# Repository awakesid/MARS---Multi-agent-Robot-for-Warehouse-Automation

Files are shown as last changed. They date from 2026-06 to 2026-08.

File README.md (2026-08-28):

# M.A.R.S — Multi Agent Robot System for Warehouse Automation

Modular multi-robot warehouse automation system using sensor fusion (encoders + overhead camera/ArUco) for localization, with ROS 2 based central coordination and ESP32-based robot firmware.

## Overview

- Differential-drive robots with ESP32 microcontrollers, encoder-based odometry, and servo grippers
- Overhead camera + ArUco markers for global pose estimation of robots, loads, and dropzones
- ROS 2 central controller handles task allocation, path planning, collision avoidance
- Robot ↔ central controller communication over UDP (JSON commands)
- Supports single/multi-robot operation, priority-based and thread-based task execution, single/double dropzone configurations

## System Architecture

```
Overhead Camera → aruco_detector (OpenCV) → /bot_poses, /loads, /dropzone
                                                      ↓
                                              task_manager (ROS 2)
                                        (task allocation, collision avoidance, navigation)
                                                      ↓
                                          UDP (JSON) ↔ ESP32 robots
```

## Hardware

- ESP32-WROOM / ESP32-S3
- N20 DC motors with encoders
- L293D dual H-bridge motor driver
- Servo gripper
- Li-Po battery
- Custom double-sided PCB (KiCad design, in-house etched)
- 3D printed chassis (Fusion 360 + Bambu Lab printer)

## Software Stack

- **Firmware**: C++ (Arduino/ESP32), non-blocking UDP + Telnet handlers, PID for straight-line motion
- **Central Controller**: ROS 2 (Python/C++), OpenCV for ArUco detection
- **Communication**: ROS 2 topics (internal), UDP/WiFi (robot control)

## Repository Structure

```
/firmware        # ESP32 robot firmware (motor control, encoder PID, UDP command handling)
/ros2_ws          # ROS 2 packages: camera_node, aruco_detector, task_manager
/pcb              # KiCad PCB design files
/cad              # Fusion 360 chassis design files
/docs             # Report, diagrams, results
```

## Firmware Command Protocol

Robots listen on a dedicated UDP port for JSON commands:

```json
{"id": 1, "cmd": "FORWARD", "dist": 200}
{"id": 1, "cmd": "TURN_L", "angle": 90}
{"id": 1, "cmd": "GRAB"}
```

Supported commands: `FORWARD`, `BACKWARD`, `TURN_L`, `TURN_R`, `GRAB`, `RELEASE`, `STOP`
Each command receives an `ack` on receipt and a `done` reply on completion. Odometry is broadcast at 10 Hz.

## Setup

### Firmware
1. Open `/firmware` in Arduino IDE / PlatformIO
2. Set `BOT_ID`, WiFi credentials, and target UDP port per robot
3. Flash to ESP32

### Central Controller
1. Requires ROS 2 (tested on Humble/Iron), OpenCV, `opencv-contrib` (ArUco module)
2. Build workspace:
   ```
   cd ros2_ws
   colcon build
   source install/setup.bash
   ```
3. Launch nodes:
   ```
   ros2 launch mars_bringup mars.launch.py
   ```

Thread-based multi-robot execution with double dropzone gave the best throughput; single dropzone increases collision risk and coordination overhead.

## Team
- Amrit Kumar Banjade
- Laxmi Prasad Upadhyaya
- Siddartha Gupta
- Sumit Sigdel

Department of Electronics and Computer Engineering, Pashchimanchal Campus, IOE, Tribhuvan University
Supervisor: Asst. Prof. Er. Hom Nath Tiwari

For a more detailed description, you can refer `MARS_report.pdf`

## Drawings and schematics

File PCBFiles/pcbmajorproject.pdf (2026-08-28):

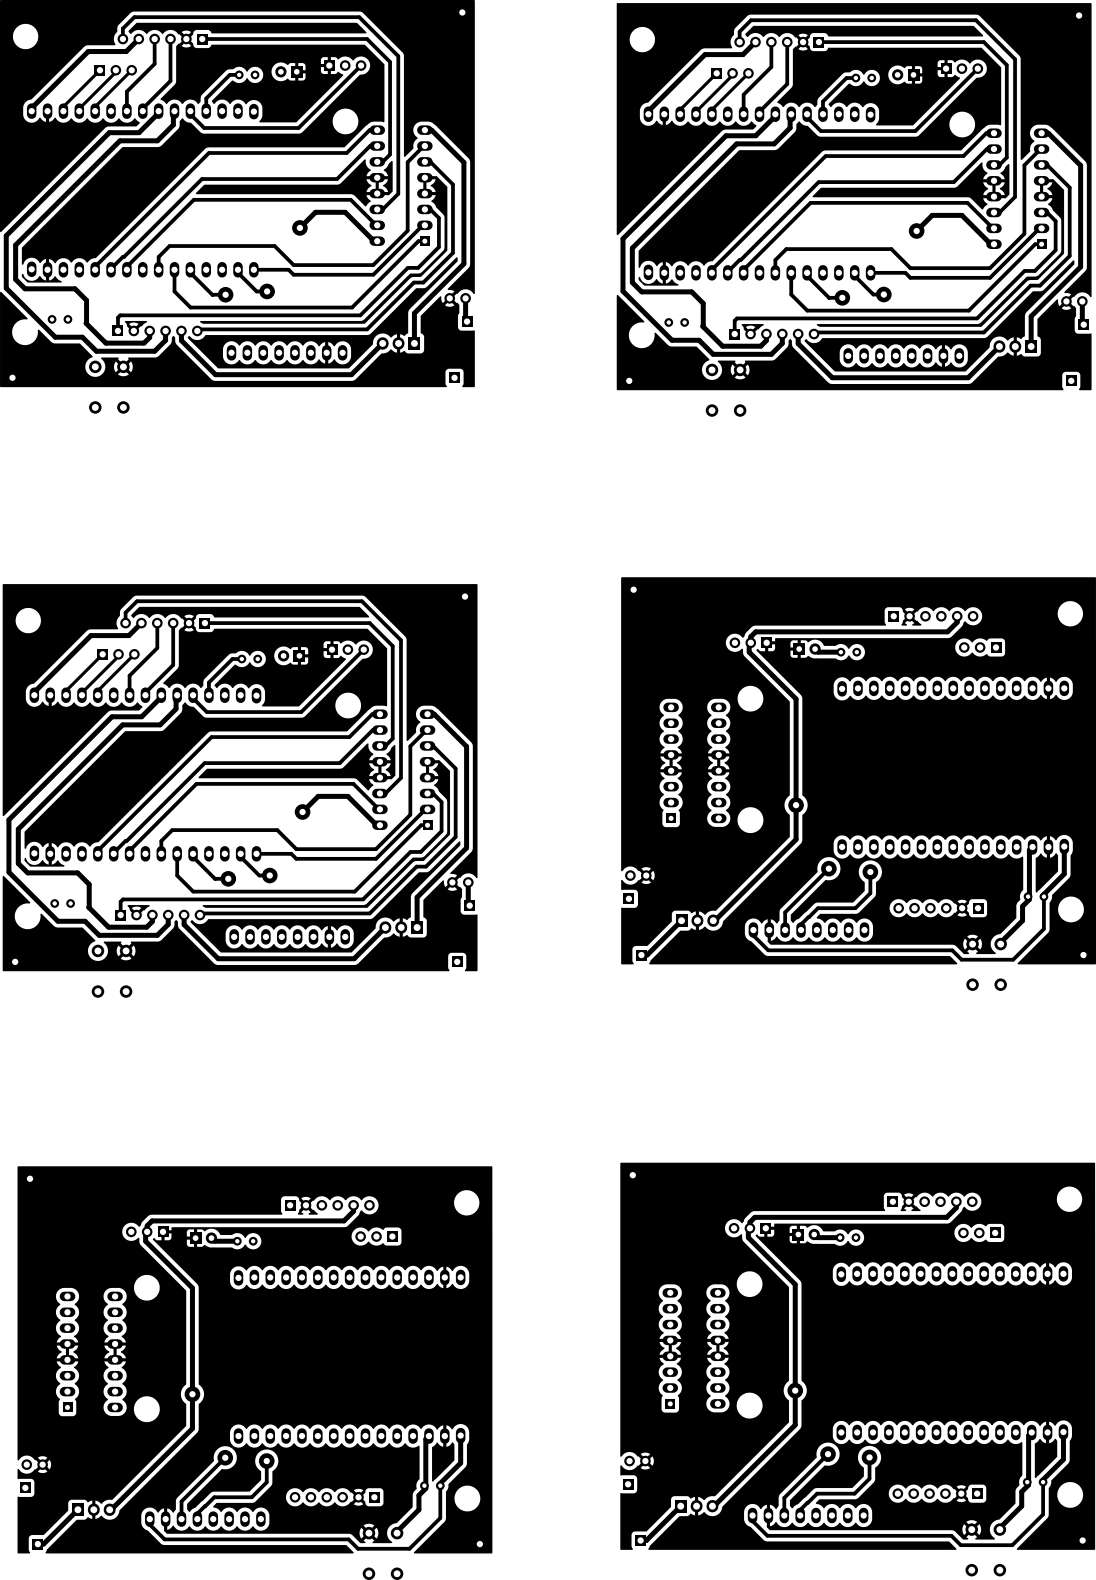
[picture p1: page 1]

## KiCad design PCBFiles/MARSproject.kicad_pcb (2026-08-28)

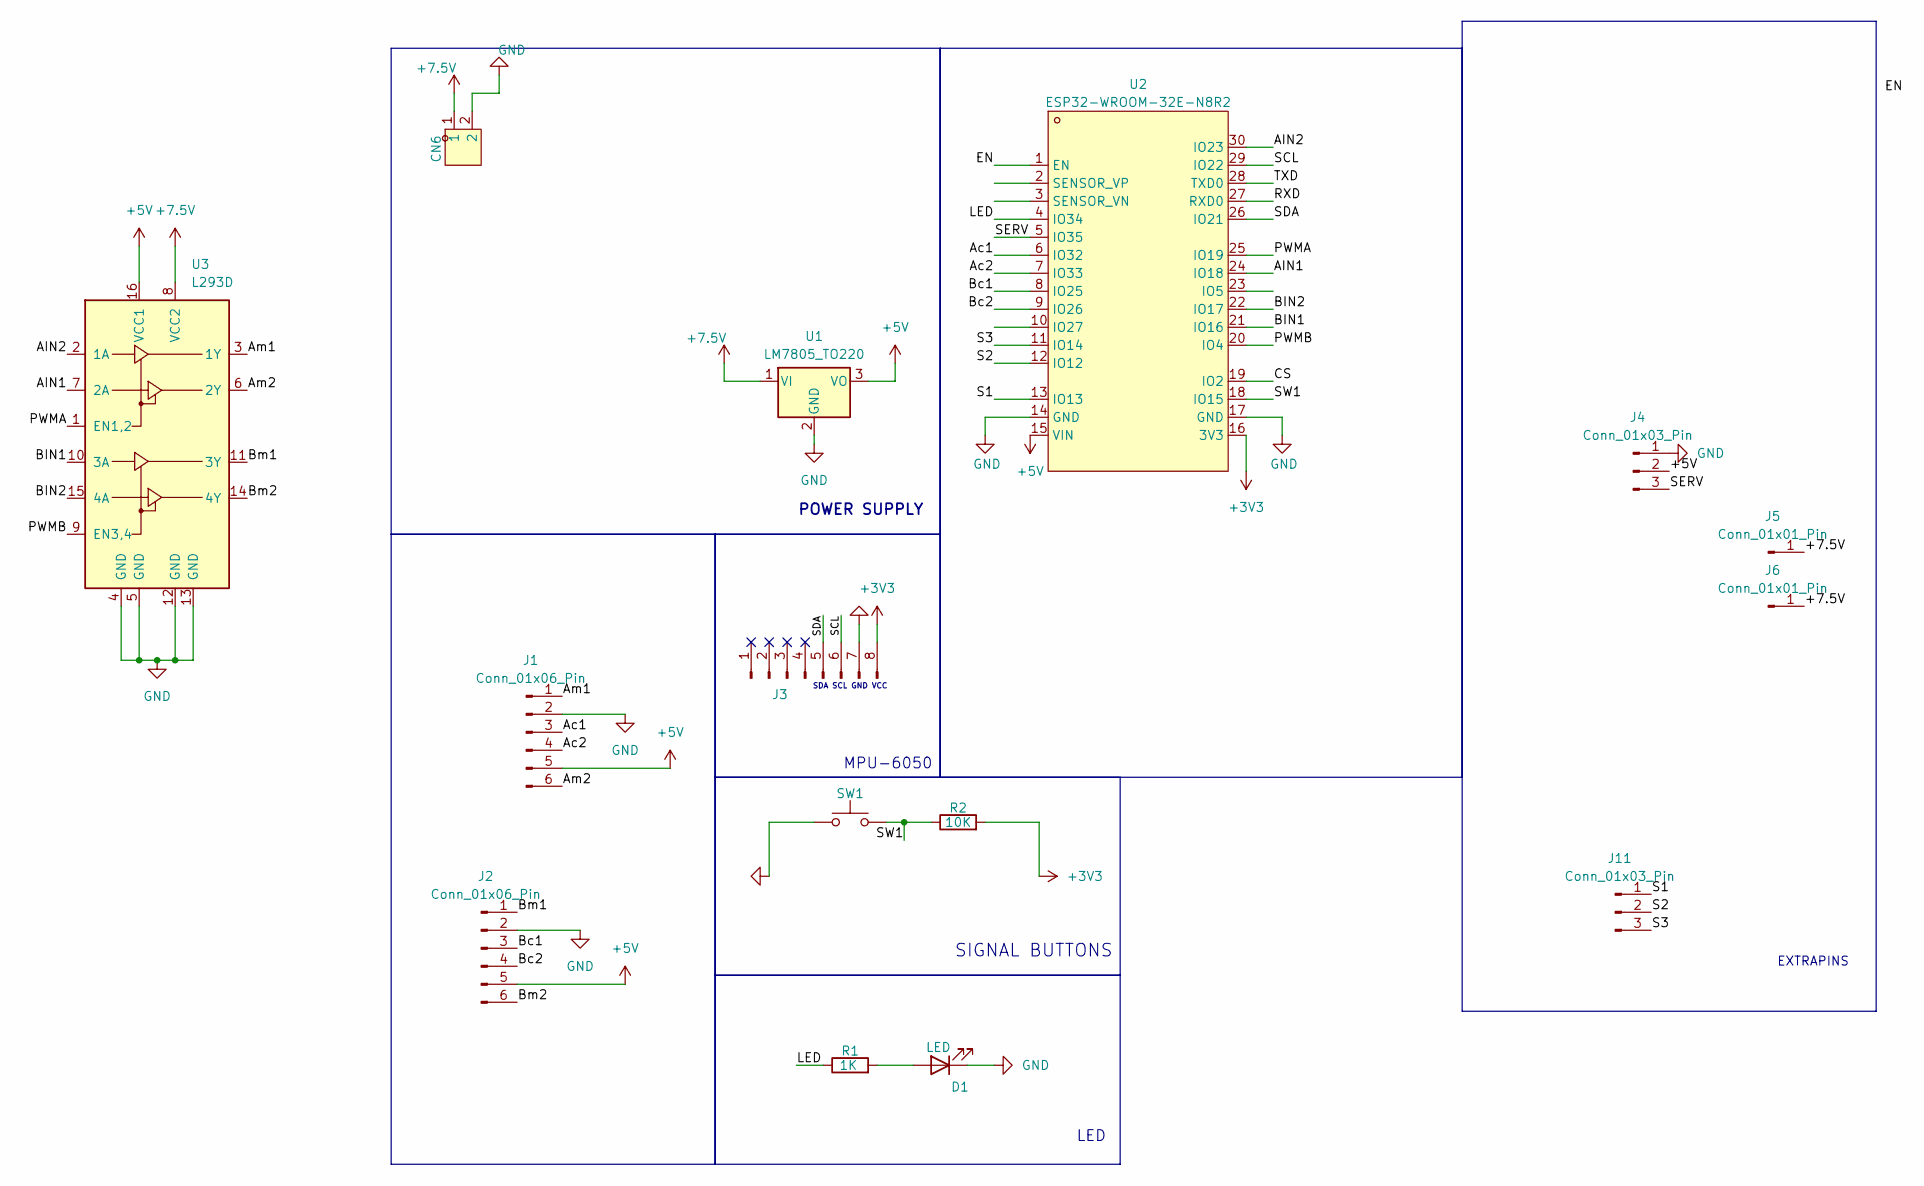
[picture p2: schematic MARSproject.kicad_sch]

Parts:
CN6: B2B-XH-A (LF)(SN); CONN-TH_B2B-XH-A-LF-SN; LCSC Part C158012
D1: LED; LED_D1.8mm_W3.3mm_H2.4mm
J1, J2: Conn_01x06_Pin; PinHeader_1x06_P2.54mm_Vertical
J3: Conn_01x08_Pin; PinHeader_1x08_P2.54mm_Vertical
J4, J11: Conn_01x03_Pin; PinHeader_1x03_P2.54mm_Vertical
J5, J6: Conn_01x01_Pin; PinHeader_1x01_P2.54mm_Vertical
R1: 1K; R_Axial_DIN0204_L3.6mm_D1.6mm_P2.54mm_Vertical
R2: 10K; R_Axial_DIN0204_L3.6mm_D1.6mm_P2.54mm_Vertical
SW1: SW_Push; SW_PUSH_6mm_H4.3mm
U1: LM7805_TO220; TO-220-3_Vertical
U2: ESP32-WROOM-32E-N8R2; esp32 dev board; LCSC Part C5361945
U3: L293D; DIP-16_W7.62mm

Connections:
+3V3: J3.8, R2.2, U2.16 (3V3)
+5V: J1.5, J2.5, J4.2, U1.3 (VO), U2.15 (VIN), U3.16 (VCC1)
+7.5V: CN6.1, J5.1, J6.1, U1.1 (VI), U3.8 (VCC2)
/AIN1: U2.24 (IO18), U3.7 (2A)
/AIN2: U2.30 (IO23), U3.2 (1A)
/Ac1: J1.3, U2.6 (IO32)
/Ac2: J1.4, U2.7 (IO33)
/Am1: J1.1, U3.3 (1Y)
/Am2: J1.6, U3.6 (2Y)
/BIN1: U2.21 (IO16), U3.10 (3A)
/BIN2: U2.22 (IO17), U3.15 (4A)
/Bc1: J2.3, U2.8 (IO25)
/Bc2: J2.4, U2.9 (IO26)
/Bm1: J2.1, U3.11 (3Y)
/Bm2: J2.6, U3.14 (4Y)
/CS: U2.19 (IO2)
/EN: U2.1 (EN)
/LED: R1.1, U2.4 (IO34)
/PWMA: U2.25 (IO19), U3.1 (EN1,2)
/PWMB: U2.20 (IO4), U3.9 (EN3,4)
/RXD: U2.27 (RXD0)
/S1: J11.1, U2.13 (IO13)
/S2: J11.2, U2.12 (IO12)
/S3: J11.3, U2.11 (IO14)
/SCL: J3.6, U2.29 (IO22)
/SDA: J3.5, U2.26 (IO21)
/SERV: J4.3, U2.5 (IO35)
/SW1: R2.1, SW1.2, U2.18 (IO15)
/TXD: U2.28 (TXD0)
GND: CN6.2, D1.1 (K), J1.2, J2.2, J3.7, J4.1, SW1.1, U1.2 (GND), U2.14 (GND), U2.17 (GND), U3.4 (GND), U3.5 (GND), U3.12 (GND), U3.13 (GND)
unnamed: D1.2 (A), R1.2

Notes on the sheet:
SDA SCL GND VCC
SIGNAL BUTTONS
MPU-6050
POWER SUPPLY
EXTRAPINS
LED

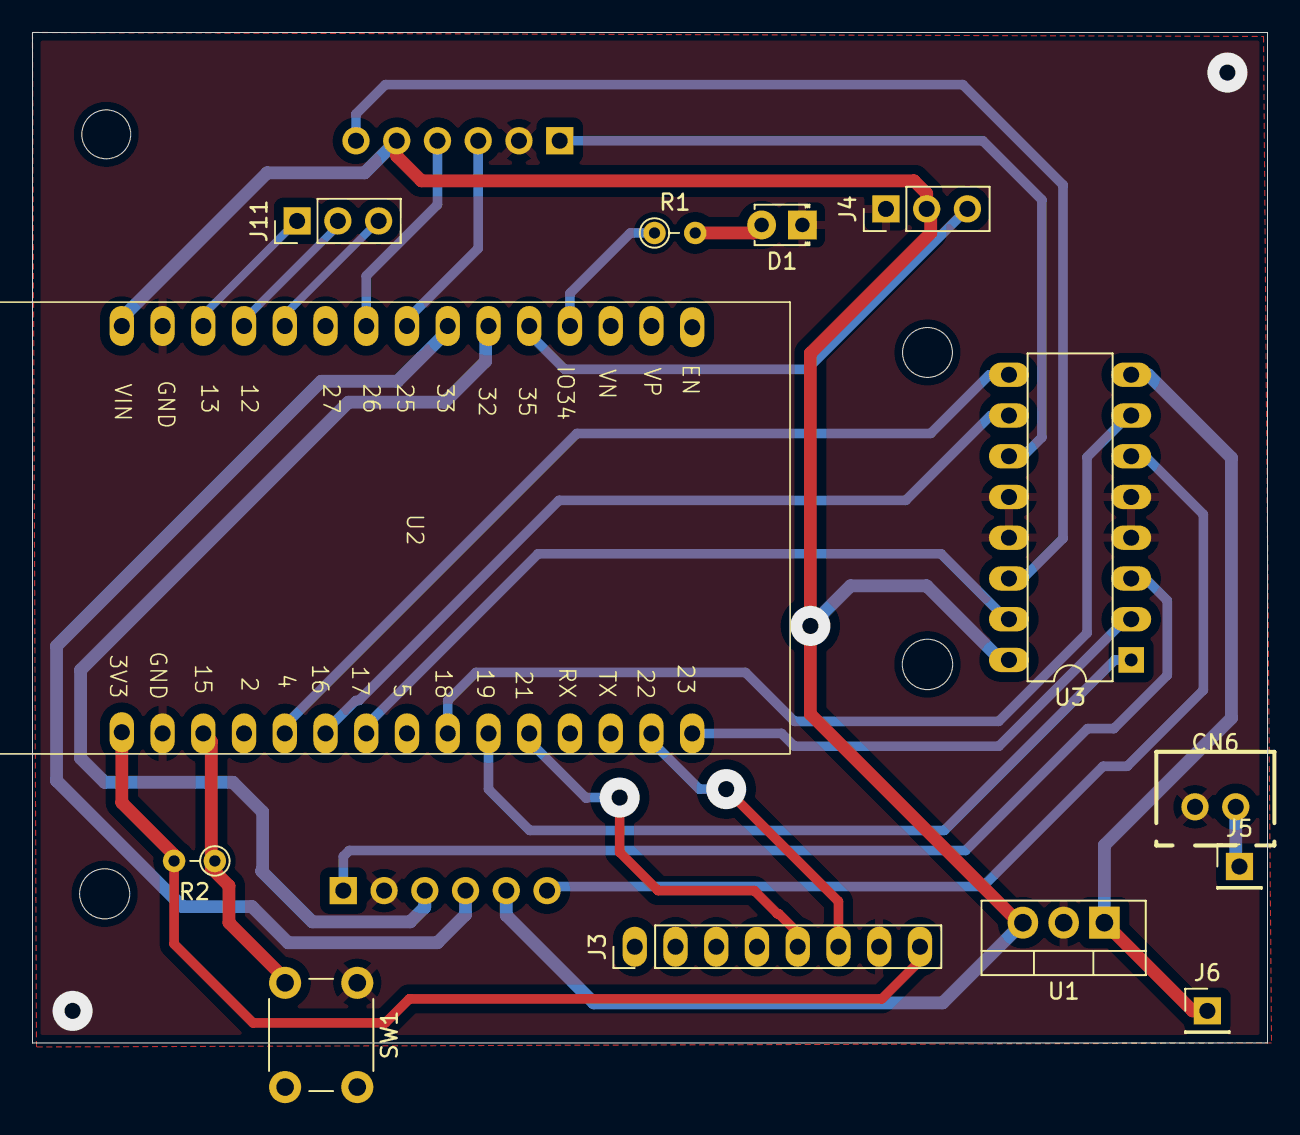
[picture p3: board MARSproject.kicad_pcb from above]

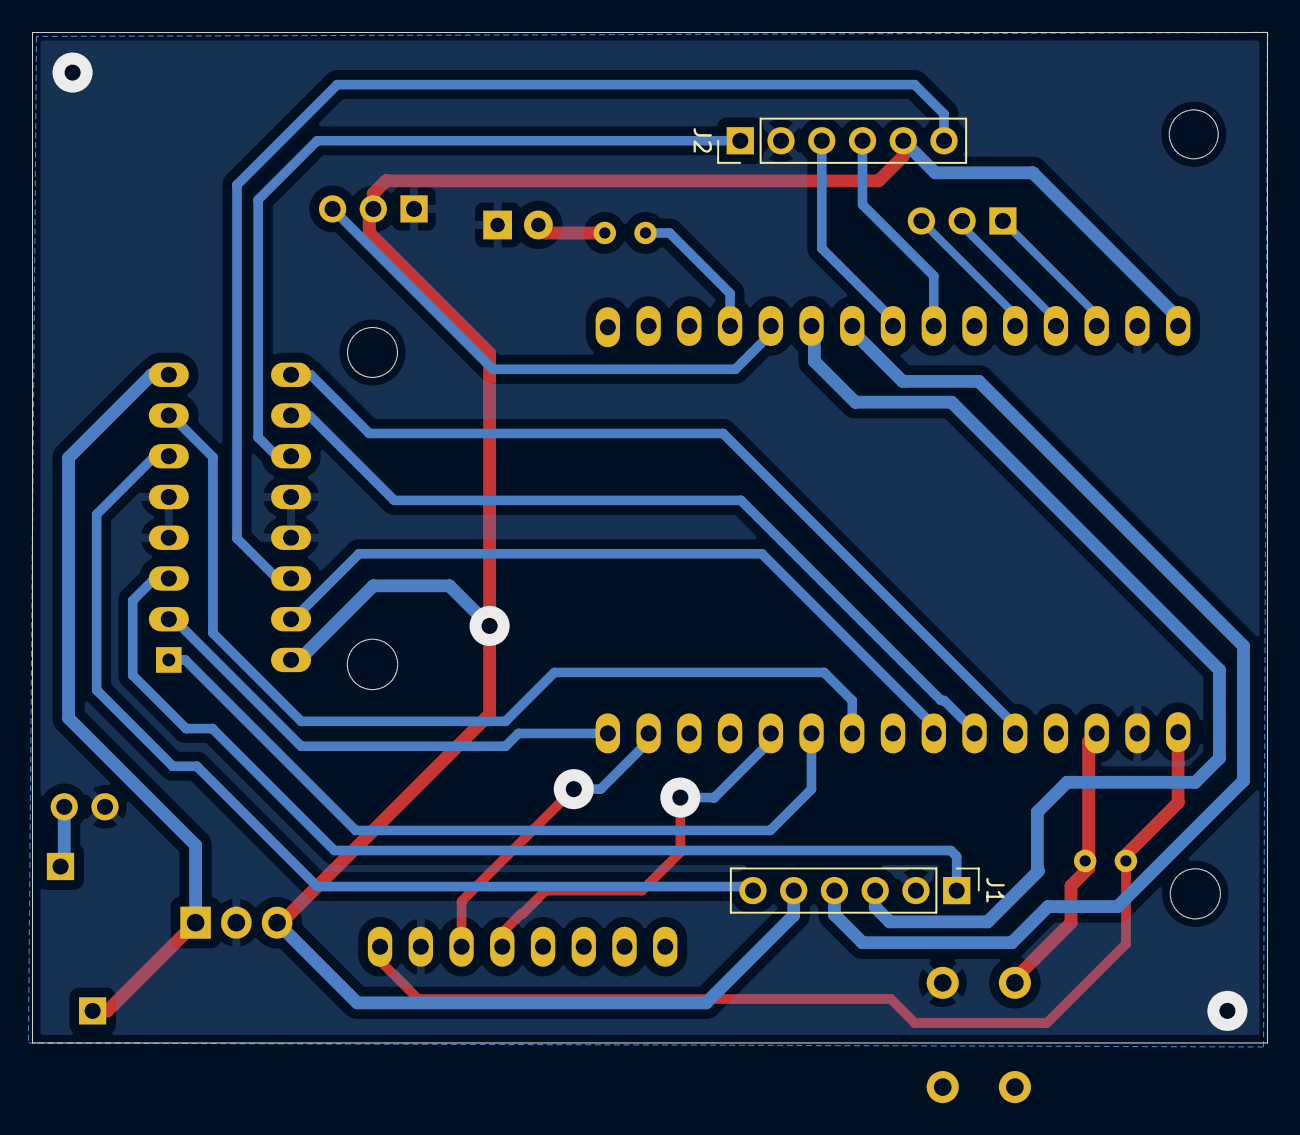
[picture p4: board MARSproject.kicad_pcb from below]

Board: 2 copper layers, 77.0 x 63.0 mm, 15 parts (2 on the bottom side), 27 nets.

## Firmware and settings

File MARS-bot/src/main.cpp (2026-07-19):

#include <Arduino.h>
#include <WiFi.h>
#include <ArduinoJson.h>


// ─── WiFi Config ─────────────────────────────────────────────────
const char* SSID     = "your ssid";
const char* PASSWORD = "your password";
const int   UDP_PORT = 4210;

// ─── Bot Identity ────────────────────────────────────────────────
const int BOT_ID = 1;  // change per bot: 1, 2, 3

// ─── Motor Pins ───────────────────────────────────────────────────
#define R_IN1   18
#define R_IN2   23
#define R_EN    19
#define L_IN1   16
#define L_IN2   17
#define L_EN    4

#define SERVO_PIN 14

// ─── Encoder Pins ────────────────────────────────────────────────
#define ENC_L_A  26
#define ENC_L_B  25
#define ENC_R_A  32
#define ENC_R_B  33

// ─── PWM ─────────────────────────────────────────────────────────
#define L_PWM_CH  0
#define R_PWM_CH  1
#define PWM_FREQ  5000
#define PWM_RES   8

#define SERVO_CH   2
#define SERVO_FREQ 50    // 50Hz standard servo

// ─── Robot Constants ─────────────────────────────────────────────
const float TICKS_PER_MM  = 6.48f;
const float TICKS_PER_DEG = 7.067f;
const int   BASE_SPEED    = 150;
const int   TURN_SPEED    = 120;
const int   MIN_SPEED     = 85;   // min PWM before motor stalls (L293D)

// ─── PID Gains (tunable via telnet) ──────────────────────────────
float Kp = 1.2f;
float Ki = 0.8f;
float Kd = 0.8f;

// ─── Encoder ─────────────────────────────────────────────────────
volatile long encL = 0;
volatile long encR = 0;

void IRAM_ATTR encL_ISR() {
  if (digitalRead(ENC_L_B)) encL++; else encL--;
}
void IRAM_ATTR encR_ISR() {
  if (digitalRead(ENC_R_B)) encR++; else encR--;
}

// ─── PID State ───────────────────────────────────────────────────
float pid_integral = 0;
float pid_last_err = 0;
unsigned long pid_last_time = 0;

// ─── Network ─────────────────────────────────────────────────────
WiFiUDP     udp;
WiFiServer  telnetServer(23);
WiFiClient  telnetClient;

IPAddress   remoteIP;
uint16_t    remotePort = 0;

// ─── Log (telnet + serial) ────────────────────────────────────────
void rlog(const char* format, ...) {
  char buf[256];
  va_list args;
  va_start(args, format);
  vsnprintf(buf, sizeof(buf), format, args);
  va_end(args);
  Serial.println(buf);
  if (telnetClient && telnetClient.connected())
    telnetClient.println(buf);
}

// ─── UDP Reply ────────────────────────────────────────────────────
void udpReply(const char* type, const char* extra = "") {
  if (remotePort == 0) return;
  char buf[128];
  snprintf(buf, sizeof(buf),
    "{\"id\":%d,\"type\":\"%s\",\"encL\":%ld,\"encR\":%ld%s}",
    BOT_ID, type, encL, encR, extra);
  udp.beginPacket(remoteIP, remotePort);
  udp.print(buf);
  udp.endPacket();
}


//---------------------------------------------
void servoSetup() {
  ledcSetup(SERVO_CH, SERVO_FREQ, 16);  // 16-bit for servo precision
  ledcAttachPin(SERVO_PIN, SERVO_CH);
}

void servoOpen() {   // 90 degrees
  ledcWrite(SERVO_CH, 7864);  // ~1.5ms pulse / 20ms * 65535
}

void servoClose() {  // 0 degrees  
  ledcWrite(SERVO_CH, 1738);  // ~0.5ms pulse / 20ms * 65535
}

// ─── Motor Control ───────────────────────────────────────────────
void stopMotors() {
  digitalWrite(L_IN1, LOW); digitalWrite(L_IN2, LOW);
  digitalWrite(R_IN1, LOW); digitalWrite(R_IN2, LOW);
  ledcWrite(L_PWM_CH, 0);
  ledcWrite(R_PWM_CH, 0);
}

void motorLeft(int spd) {
  if (spd >= 0) { digitalWrite(L_IN1, HIGH); digitalWrite(L_IN2, LOW); }
  else          { digitalWrite(L_IN1, LOW);  digitalWrite(L_IN2, HIGH); spd = -spd; }
  ledcWrite(L_PWM_CH, constrain(spd, 0, 255));
}

void motorRight(int spd) {
  if (spd >= 0) { digitalWrite(R_IN1, HIGH); digitalWrite(R_IN2, LOW); }
  else          { digitalWrite(R_IN1, LOW);  digitalWrite(R_IN2, HIGH); spd = -spd; }
  ledcWrite(R_PWM_CH, constrain(spd, 0, 255));
}

// ─── PID ─────────────────────────────────────────────────────────
void resetPID() {
  pid_integral = 0; pid_last_err = 0; pid_last_time = millis();
}

int pidCalc(float err) {
  unsigned long now = millis();
  float dt = (now - pid_last_time) / 1000.0f;
  if (dt < 0.001f) dt = 0.02f;
  pid_last_time = now;
  pid_integral += err * dt;
  float deriv = (err - pid_last_err) / dt;
  pid_last_err = err;
  return (int)constrain(Kp*err + Ki*pid_integral + Kd*deriv, -80, 80);
}

// ─── Odometry Send (10Hz) ─────────────────────────────────────────
unsigned long lastOdomMs = 0;
void sendOdom() {
  if (millis() - lastOdomMs < 100) return;
  lastOdomMs = millis();
  udpReply("odom");
}

// ════════════════════════════════════════════════════════════════
//  MOVE FORWARD
// ════════════════════════════════════════════════════════════════
void moveForward(float dist_mm, int speed) {
  long target = (long)(dist_mm * TICKS_PER_MM);
  encL = encR = 0;
  resetPID();
  rlog("[FWD] %.0fmm → %ld ticks", dist_mm, target);
  udpReply("ack");

  while (true) {
    long avg = (abs(encL) + abs(encR)) / 2;
    if (avg >= target) break;

    // slow down last 15%
    long rem = target - avg;
    int spd = speed;
    if (rem < target * 0.15f)
      spd = max(MIN_SPEED, (int)(speed * (float)rem / (target * 0.15f)));

    float err = (float)(encL - encR);
    int   cor = pidCalc(err);
    motorLeft (spd - cor);
    motorRight(spd + cor);

    sendOdom();
    delay(20);
  }
  stopMotors();
  rlog("[FWD] done encL:%ld encR:%ld", encL, encR);
  udpReply("done");
}

// ════════════════════════════════════════════════════════════════
//  MOVE BACKWARD
// ════════════════════════════════════════════════════════════════
void moveBackward(float dist_mm, int speed) {
  long target = (long)(dist_mm * TICKS_PER_MM);
  encL = encR = 0;
  resetPID();
  rlog("[BWD] %.0fmm target:%ld ticks", dist_mm, target);
  udpReply("ack");
 
  while (true) {
    // use abs() — backward encoders count negative
    long absL = abs(encL);
    long absR = abs(encR);
    long avg  = (absL + absR) / 2;
    if (avg >= target) break;
 
    long rem = target - avg;
    int spd = speed;
    if (rem < target * 0.15f)
      spd = max(MIN_SPEED, (int)(speed * (float)rem / (target * 0.15f)));
 
    // // error: difference between how far each wheel has travelled
    // // use abs counts so sign is consistent regardless of direction
    // float err = (float)(absL - absR);
    // int   cor = pidCalc(err);
 
    // clamp correction so neither motor drops below MIN_SPEED
    // cor = constrain(cor, -(spd - MIN_SPEED), (spd - MIN_SPEED));
 
    // negative speed = backward for motorLeft/motorRight
    motorLeft (-spd );
    motorRight(-spd );
 
    sendOdom();
    delay(20);
  }
  stopMotors();
  rlog("[BWD] done encL:%ld encR:%ld", encL, encR);
  udpReply("done");
}


// ════════════════════════════════════════════════════════════════
//  TURN  — with overshoot correction
//  dir: +1 = left,  -1 = right
// ════════════════════════════════════════════════════════════════
void executeTurn(float angle_deg, int dir) {
  long target = (long)(angle_deg * TICKS_PER_DEG);
  encL = encR = 0;

  // ── Phase 1: main turn ────────────────────────────────────────
  while (true) {
    long avg = (abs(encL) + abs(encR)) / 2;
    if (avg >= target) break;

    long rem = target - avg;
    int spd = TURN_SPEED;
    if (rem < target * 0.25f)
      spd = max(MIN_SPEED, (int)(TURN_SPEED * (float)rem / (target * 0.25f)));

    // dir +1 LEFT:  left back,  right fwd
    // dir -1 RIGHT: left fwd,   right back
    motorLeft (dir * (-spd));
    motorRight(dir * spd);

    sendOdom();
    delay(20);
  }
  stopMotors();
  delay(80);  // let bot settle mechanically

  // ── Phase 2: overshoot correction (±15 ticks tolerance) ───────
  long avg = (abs(encL) + abs(encR)) / 2;
  long error = avg - target;
  rlog("[TURN] landed:%ld target:%ld error:%ld", avg, target, error);

  if (abs(error) > 15) {
    // nudge back in opposite direction
    int nudgeDir = (error > 0) ? -dir : dir;
    encL = encR = 0;
    long nudgeTicks = abs(error);

    rlog("[TURN] correcting %ld ticks...", nudgeTicks);
    while (true) {
      long navg = (abs(encL) + abs(encR)) / 2;
      if (navg >= nudgeTicks) break;
      motorLeft (nudgeDir * (-MIN_SPEED));
      motorRight(nudgeDir *  MIN_SPEED);
      delay(10);
    }
    stopMotors();
    delay(50);
  }

  rlog("[TURN] done. encL:%ld encR:%ld", encL, encR);
  udpReply("done");
}

void turnLeft(float angle_deg)  { 
  rlog("[TURNL] %.1f deg", angle_deg);
  udpReply("ack");
  executeTurn(angle_deg, +1); 
}
void turnRight(float angle_deg) { 
  rlog("[TURNR] %.1f deg", angle_deg);
  udpReply("ack");
  executeTurn(angle_deg, -1); 
}

// ════════════════════════════════════════════════════════════════
//  UDP PACKET HANDLER
// ════════════════════════════════════════════════════════════════
/*
  Expected JSON from app/ROS:
  {"id":1, "cmd":"FORWARD",   "dist":200}
  {"id":1, "cmd":"BACKWARD",  "dist":150}
  {"id":1, "cmd":"TURN_L",    "angle":90}
  {"id":1, "cmd":"TURN_R",    "angle":90}
  {"id":1, "cmd":"STOP"}

  Replies:
  {"id":1, "type":"ack",  "encL":0,    "encR":0}
  {"id":1, "type":"odom", "encL":1234, "encR":1230}
  {"id":1, "type":"done", "encL":1296, "encR":1292}
*/
void handleUDP() {
  int sz = udp.parsePacket();
  if (!sz) return;

  char buf[256];
  int len = udp.read(buf, sizeof(buf) - 1);
  buf[len] = '\0';

  remoteIP   = udp.remoteIP();
  remotePort = udp.remotePort();

  rlog("[UDP] %s", buf);

  JsonDocument doc;
  if (deserializeJson(doc, buf) != DeserializationError::Ok) {
    rlog("[UDP] bad JSON");
    return;
  }

  // extract first, then compare — ArduinoJson v7 MemberProxy is non-copyable
  int         id   = doc["id"]    | 0;
  const char* cmd  = doc["cmd"]   | "";
  float       dist = doc["dist"]  | 200.0f;
  float       ang  = doc["angle"] | 90.0f;

  if (id != BOT_ID) return;

  if      (strcmp(cmd, "FORWARD")  == 0) moveForward (dist, BASE_SPEED);
  else if (strcmp(cmd, "BACKWARD") == 0) moveBackward(dist, BASE_SPEED);
  else if (strcmp(cmd, "TURN_L")   == 0) turnLeft    (ang);
  else if (strcmp(cmd, "TURN_R")   == 0) turnRight   (ang);
  else if (strcmp(cmd, "GRAB")    == 0) {
  servoClose();
  rlog("[GRAB]");
  udpReply("done");
}
  else if (strcmp(cmd, "RELEASE") == 0) {
  servoOpen();
  rlog("[RELEASE]");
  udpReply("done");
}
  else if (strcmp(cmd, "STOP")     == 0) {
    stopMotors();
    rlog("[STOP]");
    udpReply("stopped");
  }
  else rlog("[UDP] unknown cmd: %s", cmd);
}

// ════════════════════════════════════════════════════════════════
//  TELNET HANDLER (PID tuning)
// ════════════════════════════════════════════════════════════════
void printHelp() {
  rlog("── Telnet Commands ──────────────────");
  rlog(" kp <v>   set Kp     e.g. kp 1.5");
  rlog(" ki <v>   set Ki     e.g. ki 0.01");
  rlog(" kd <v>   set Kd     e.g. kd 0.3");
  rlog(" pid      show PID values");
  rlog(" enc      show encoder counts");
  rlog(" stop     stop motors");
  rlog(" help     this menu");
  rlog("─────────────────────────────────────");
}

void handleTelnet() {
  if (telnetServer.hasClient()) {
    if (!telnetClient || !telnetClient.connected()) {
      telnetClient = telnetServer.available();
      rlog("=== MARS Monitor Connected ===");
      rlog("Bot ID:%d  IP:%s", BOT_ID, WiFi.localIP().toString().c_str());
      rlog("Kp=%.3f Ki=%.3f Kd=%.3f", Kp, Ki, Kd);
      printHelp();
    }
  }

  if (!telnetClient || !telnetClient.connected()) return;
  if (!telnetClient.available()) return;

  String line = telnetClient.readStringUntil('\n');
  line.trim();
  if (!line.length()) return;

  if      (line.startsWith("kp ")) { Kp = line.substring(3).toFloat(); rlog("[PID] Kp=%.4f Ki=%.4f Kd=%.4f", Kp, Ki, Kd); }
  else if (line.startsWith("ki ")) { Ki = line.substring(3).toFloat(); rlog("[PID] Kp=%.4f Ki=%.4f Kd=%.4f", Kp, Ki, Kd); }
  else if (line.startsWith("kd ")) { Kd = line.substring(3).toFloat(); rlog("[PID] Kp=%.4f Ki=%.4f Kd=%.4f", Kp, Ki, Kd); }
  else if (line == "pid")          { rlog("[PID] Kp=%.4f Ki=%.4f Kd=%.4f", Kp, Ki, Kd); }
  else if (line == "enc")          { rlog("[ENC] L:%ld R:%ld", encL, encR); }
  else if (line == "stop")         { stopMotors(); rlog("[STOP]"); }
  else if (line == "help")         { printHelp(); }
  else                             { rlog("[?] unknown: %s", line.c_str()); }
}

// ════════════════════════════════════════════════════════════════
void setup() {
  Serial.begin(115200);

  pinMode(L_IN1, OUTPUT); pinMode(L_IN2, OUTPUT);
  pinMode(R_IN1, OUTPUT); pinMode(R_IN2, OUTPUT);

  ledcSetup(L_PWM_CH, PWM_FREQ, PWM_RES);
  ledcSetup(R_PWM_CH, PWM_FREQ, PWM_RES);
  ledcAttachPin(L_EN, L_PWM_CH);
  ledcAttachPin(R_EN, R_PWM_CH);

  pinMode(ENC_L_A, INPUT_PULLUP); pinMode(ENC_L_B, INPUT_PULLUP);
  pinMode(ENC_R_A, INPUT_PULLUP); pinMode(ENC_R_B, INPUT_PULLUP);
  attachInterrupt(digitalPinToInterrupt(ENC_L_A), encL_ISR, RISING);
  attachInterrupt(digitalPinToInterrupt(ENC_R_A), encR_ISR, RISING);

  stopMotors();
  servoSetup();
  servoOpen(); 
  WiFi.begin(SSID, PASSWORD);
  Serial.print("WiFi connecting");
  while (WiFi.status() != WL_CONNECTED) { delay(500); Serial.print("."); }
  Serial.printf("\nIP: %s\n", WiFi.localIP().toString().c_str());

  udp.begin(UDP_PORT);
  telnetServer.begin();

  Serial.printf("UDP  port: %d\n", UDP_PORT);
  Serial.println("Telnet:  nc <IP> 23");
  Serial.println("Ready.");
}

void loop() {
  handleUDP();
  handleTelnet();
}

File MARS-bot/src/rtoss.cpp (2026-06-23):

#include<Arduino.h>
#include <Servo.h>


# define trigpin1 22
# define echopin1 23

# define trigpin2 44
# define echopin2 43

# define servopin1 33
# define servopin2 22


QueueHandle_t queue;

typedef struct{
   int trigpin;
   int echopin;
   const char * name;
}sensor_cfg;


typedef struct{
    int servopin;
    const char *name;

}servo_cfg;

typedef struct{
    int dist;
    int detected;
}sens_msg;


float getDistance(int trig, int echo) {
    digitalWrite(trig, LOW);
    delayMicroseconds(2);
    digitalWrite(trig, HIGH);
    delayMicroseconds(10);
    digitalWrite(trig, LOW);

    long duration = pulseIn(echo, HIGH, 30000);
    if (duration == 0) return -1;

    return (duration * 0.0343f) / 2.0f;
}



void sensorTask(void*pvParameters){

    sensor_cfg *scfg= (sensor_cfg*)pvParameters;

    pinMode(scfg->echopin,OUTPUT);
    pinMode(scfg->trigpin,OUTPUT);

    while(1){
        float distance = getDistance(scfg->trigpin, scfg->echopin);
        sens_msg msg{
            .dist=distance,
            .detected=(distance > 0 && distance < 20) ? 1 : 0
        };

        xQueueSend(queue,&msg,portMAX_DELAY);

        vTaskDelayUntil(&xLastWake, pdMS_TO_TICKS(300));
    }



}

void servoTask(void *pvParameters){
    servo_cfg *ser=(servo_cfg*)pvParameters;
    sens_msg msg;
    Servo (ser->name).attach(ser->name);


    while(1){

        xQueueReceive(queue, &msg, portMAX_DELAY);

        if (msg.detected){
            (ser->name).write(90);
        }
        else {
            (ser->name).write(90);

        }


    }
}


static servo_cfg servo1={.name="servo1",.servopin=servopin1};
static servo_cfg servo2={.name="servo2",.servopin=servopin2};
static sensor_cfg sense1={.echopin=echopin1,.trigpin=trigpin1,.name="sensor1"};
static sensor_cfg sense2={.echopin=echopin2,.trigpin=trigpin2,.name="sensor2"};


}

void setup(){

     xQueue = xQueueCreate(5, sizeof(SensorMsg_t));
     xTaskCreate(sensorTask,"sensortask1",2048,&sense1,2,NULL);
     xTaskCreate(sensorTask,"sensortask2",2048,&sense2,2,NULL);
     xTaskCreate(servoTask,"sercotask1",2048,&servo1,1,NULL);
     xTaskCreate(servoTask,"servotask2",2048,&servo2,1,NULL);


    



}

void loop(){
    vTaskDelay(portMAX_DELAY);
}

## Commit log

2026-07-19 Replace WiFi SSID and password with placeholders
    Updated WiFi credentials to placeholders for security.
    [main.cpp]
2026-08-28 MARS PCB Files
    [MARSproject.kicad_pcb, MARSproject.kicad_sch]
